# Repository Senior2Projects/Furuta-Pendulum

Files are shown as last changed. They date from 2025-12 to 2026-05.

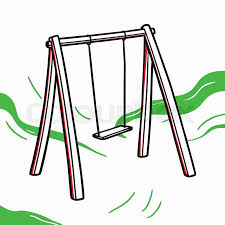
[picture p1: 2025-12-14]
Simulink_Bodies/Submission/Simulation_MCT411_T14/swing.jpg

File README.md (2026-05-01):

# Furuta Pendulum — Hybrid Control System

> **MCT411: Hybrid Control | Fall 2025 | Team 14**  
> Ain Shams University — Faculty of Engineering, Mechatronics Department

---

## 📖 Overview

This repository contains the MATLAB/Simulink implementation of a **hybrid control system** for the **Furuta (Rotary Inverted) Pendulum** — a nonlinear, underactuated mechatronic benchmark system. The control architecture combines two distinct strategies:

1. **Energy-Based Swing-Up Controller** — pumps energy into the pendulum to drive it from the natural downward-stable position to the upright equilibrium.
2. **Linear Quadratic Regulator (LQR)** — takes over once the pendulum is near upright, maintaining stability against small disturbances.

The full system is validated through both **MATLAB/Simulink simulation** and **Hardware-in-the-Loop (HIL)** testing on a physical prototype.

---

## 🧑‍💻 Team

| Name | ID | Contribution |
|---|---|---|
| Abdelghaffar Essam Abdelghaffar | 2100428 | Mechanical Design, LQR Implementation |
| Ingy Ahmed Sherif | 2100648 | LQR Implementation, Simulation Setup |
| Kareem Saleh Hassan | 2100909 | Mechanical Design, Swing-Up Implementation |
| Mariam Mohamed El Sebaey | 2100260 | Swing-Up Implementation, Simulation Setup |

---

## ⚙️ System Description

The Furuta Pendulum consists of two arms whose rotary axes are perpendicular to each other:

- **Arm 1 (Table/Rotor):** Horizontal arm driven by a DC motor. Angle: θ₁
- **Arm 2 (Pendulum):** Vertical free-swinging arm attached to the end of Arm 1. Angle: θ₂

The system is **underactuated** — only one torque input (the motor) controls two degrees of freedom.

### Hardware Components

| Component | Specification |
|---|---|
| Microcontroller | ESP32 |
| Motor Driver | H-Bridge (bidirectional) |
| Motor Encoder | 600 PPR (horizontal arm θ₁) |
| Pendulum Encoder | High-resolution (pendulum angle θ₂) |
| Power Supply | 12 V DC |
| Host Interface | USB/Serial → MATLAB/Simulink HIL |

### Physical Parameters

| Parameter | Symbol | Value |
|---|---|---|
| Pendulum mass | mᵣ | 0.018 kg |
| Pendulum COM to rotation axis | lᵣ | 0.0638 m |
| Pendulum moment of inertia | Jᵣ | 9.83 × 10⁻⁵ kg·m² |
| Table rotation axis to pendulum pivot | lₜ | 0.07 m |
| Rotor moment of inertia | J_motor | 0.0024 kg·m² |
| Motor resistance | Rₐ | 5.8466 Ω |
| Motor constants | kₜ = k_b | 0.048 V/rpm |
| Armature inductance | Lₐ | 9.15 × 10⁻⁴ H |

> Friction coefficients (motor, pendulum, table) were identified via **parameter estimation** rather than theoretical derivation.

---

## 🎮 Control Architecture

### State Vector

```
x = [θ₁  θ̇₁  θ₂  θ̇₂]ᵀ
```

### 1. Swing-Up Controller (Energy-Based)

The controller injects energy by oscillating the horizontal arm, guided by the difference between the current pendulum energy and the target energy at the upright equilibrium:

```
E  = ½ Jᵣ θ̇₁² + mᵣ g lᵣ (1 + cos θ₁)
Eᵣ = 2 mᵣ g lᵣ

u  = sat( k_swing · (Eᵣ − E) · θ̇₁ · cos θ₁ )
```

### 2. Balancing Controller (LQR)

The nonlinear Simscape Multibody model is linearized at the upright equilibrium using **Simulink Model Linearizer**, yielding the state-space matrices used for LQR design:

```
ẋ = Ax + Bu
```

**LQR Cost Function:**
```
J = ∫₀^∞ (xᵀQx + uᵀRu) dt
```

**Tuned Weights:**
```
Q = diag([1, 0.1, 100, 10])
R = 100
```

**Resulting Gain:**
```
K = [−0.0100  −0.0857  1.5880  0.1478]
u(t) = −K x(t)
```

### 3. Supervisory Logic (Stateflow)

A Stateflow chart manages transitions between control modes:

```
Swing_Up ──(|θ₂| ≤ 15°, |θ̇₂| ≤ 7)──► LQR
   ▲                                      │
   │                                      │ (|θ̇₂| ≥ 25 or timeout)
   │                                      ▼
   └────────(safe)────────────────── Recovery
```

| State | Condition |
|---|---|
| **Swing_Up** | Default; energy injection active |
| **LQR** | `\|θ₂\| ≤ 15°` and `\|θ̇₂\| ≤ 7 rad/s` |
| **Recovery** | `\|θ₂\| ≥ 110°` or speed exceeded; motor halted |

---

## 📁 Repository Structure

```
furuta-pendulum/
├── Simulink/
│   ├── SwingUp_Model.slx          # Energy-based swing-up subsystem
│   ├── LQR_Model.slx              # LQR balancing subsystem
│   ├── FullSystem_Model.slx       # Complete hybrid model with Stateflow
│   └── Pendulum_SimMechanics.slx  # Simscape Multibody physical model
├── MATLAB/
│   ├── parameters.m               # System physical parameters
│   ├── lqr_design.m               # LQR gain computation (K, Q, R)
│   └── linearize_model.m          # Linearization script
├── ESP32/
│   └── firmware/                  # Microcontroller code for HIL
├── Results/
│   ├── simulation_results.png
│   └── real_life_results.png
├── Report/
│   └── T14_Hybrid_Project_Report.pdf
└── README.md
```

---

## 🚀 Getting Started

### Requirements

- MATLAB R2022b or later
- Simulink
- Simscape & Simscape Multibody toolboxes
- Control System Toolbox (for `lqr()`)
- Stateflow

### Running the Simulation

1. Clone the repository:
   ```bash
   git clone https://github.com/<your-org>/furuta-pendulum.git
   cd furuta-pendulum
   ```

2. Open MATLAB and run the parameter initialization script:
   ```matlab
   run('MATLAB/parameters.m')
   ```

3. Open and run the full Simulink model:
   ```matlab
   open('Simulink/FullSystem_Model.slx')
   ```

4. Press **Run** in Simulink. Observe the four scopes: `PendAngle`, `PendVel`, `MotorAngle`, `MotorVel`.

### HIL Deployment (ESP32)

1. Flash the ESP32 firmware from `ESP32/firmware/`.
2. Connect via USB to the host PC.
3. In Simulink, configure the serial port in the ESP32 communication block.
4. Run the model in **External Mode** for real-time HIL control.

---

## 📊 Results Summary

| Metric | Simulation | Real-Life |
|---|---|---|
| Swing-up success | ✅ | ✅ |
| LQR stabilization | ✅ | ✅ |
| Settling time | ~7 s | ~12 s |
| Post-stabilization oscillations | Low | Slightly higher |

The discrepancies between simulation and real-life results are attributed to unmodeled joint backlash, high-frequency friction, and minor actuation delays.

---

## 📐 Controller Requirements

| Requirement | Specification |
|---|---|
| Swing-Up | Move pendulum to upright |
| Stabilization | Maintain upright via LQR |
| Sampling rate | ≥ 0.1 kHz |
| Torque limits | Motor saturation constraints |
| Robustness | Against small disturbances |

---

## 📚 References

- B. Yao, *"Modeling of Rotary Inverted Pendulum,"* 2022.
- K. J. Åström & K. Furuta, *"Swinging up a pendulum by energy control,"* Automatica, 2000.

---

## 📄 License

This project is submitted as academic coursework for MCT411 at Ain Shams University. All rights reserved by the authors.

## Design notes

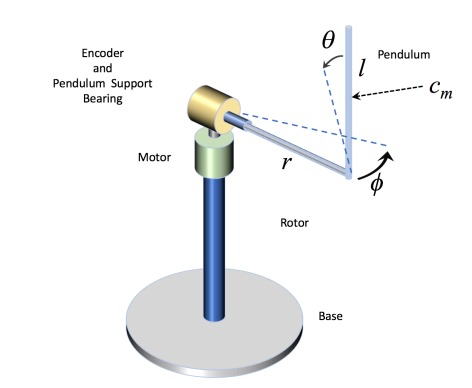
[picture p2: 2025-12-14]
Simulink_Bodies/Trial_5/Furuta_Schematic_1.jpg

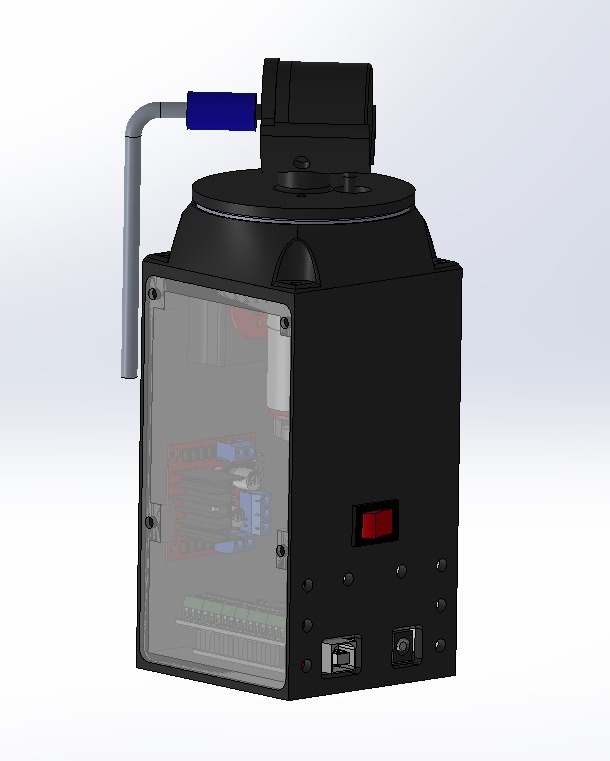
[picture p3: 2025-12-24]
Simulink_Bodies/Submission/Simulation_MCT411_T14/Model.jpeg

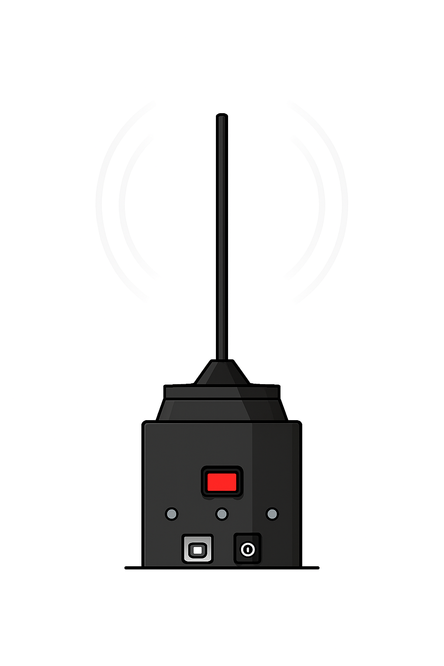
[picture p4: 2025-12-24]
Simulink_Bodies/Submission/Simulation_MCT411_T14/Model_Animated2.png

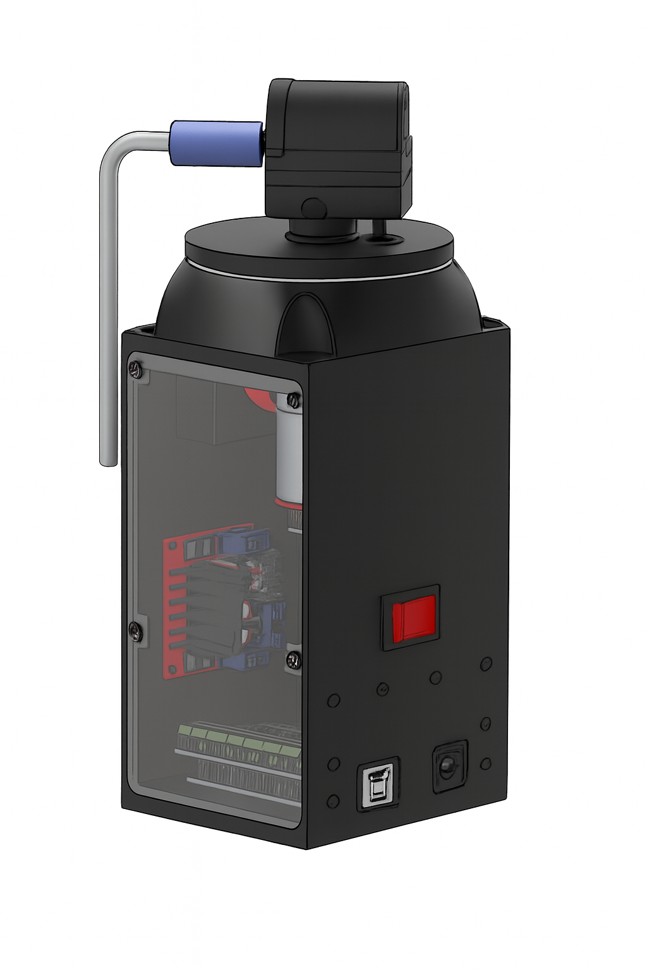
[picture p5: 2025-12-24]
Simulink_Bodies/Submission/Simulation_MCT411_T14/Model_Animated.png

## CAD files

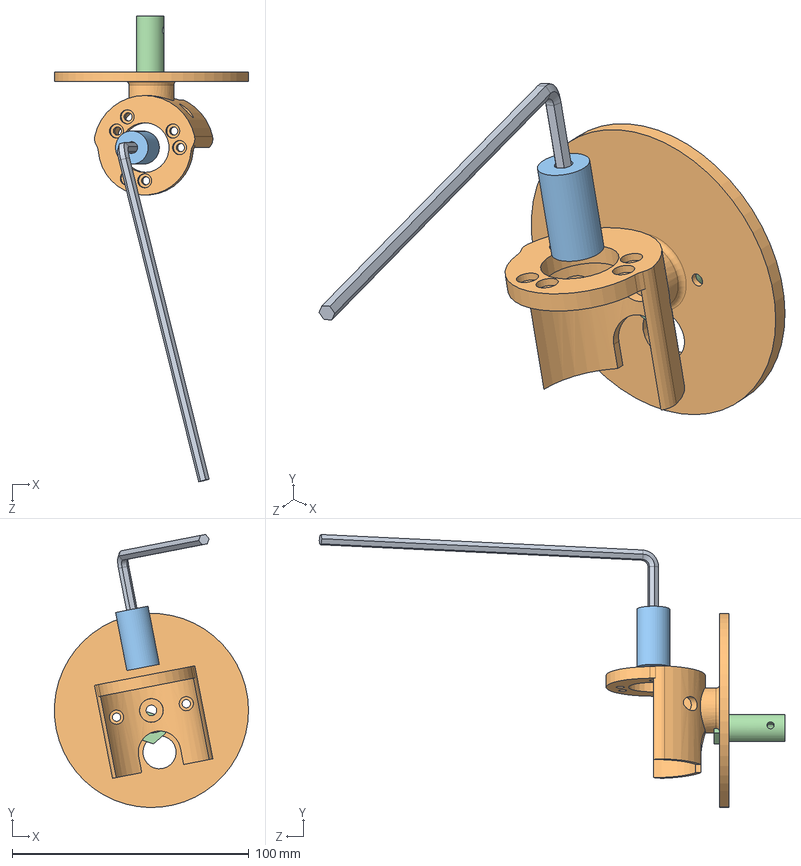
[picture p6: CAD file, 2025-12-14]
Simulink_Assembley/Furuta_Project_Assembelly.SLDASM
81.9 x 115.3 x 196.7 mm
hexa
coupler
Encoder Holder
rod

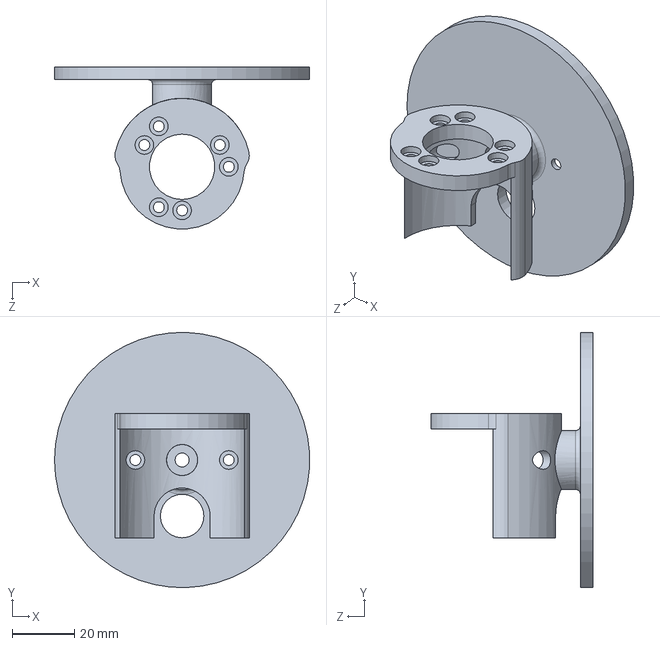
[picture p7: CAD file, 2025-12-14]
Encoder Holder.SLDPRT
81.9 x 82.0 x 51.9 mm

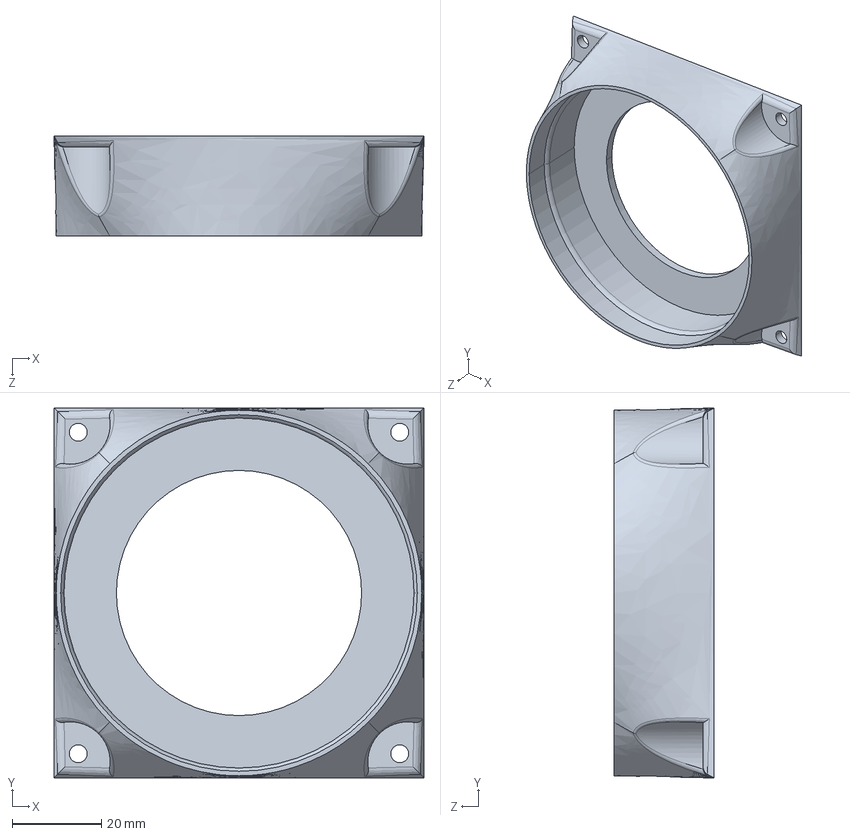
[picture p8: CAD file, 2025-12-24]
Simulink_Bodies/Submission/Simulation_MCT411_T14/Bearing Holder_Default_sldprt.STEP
83.0 x 83.0 x 22.5 mm

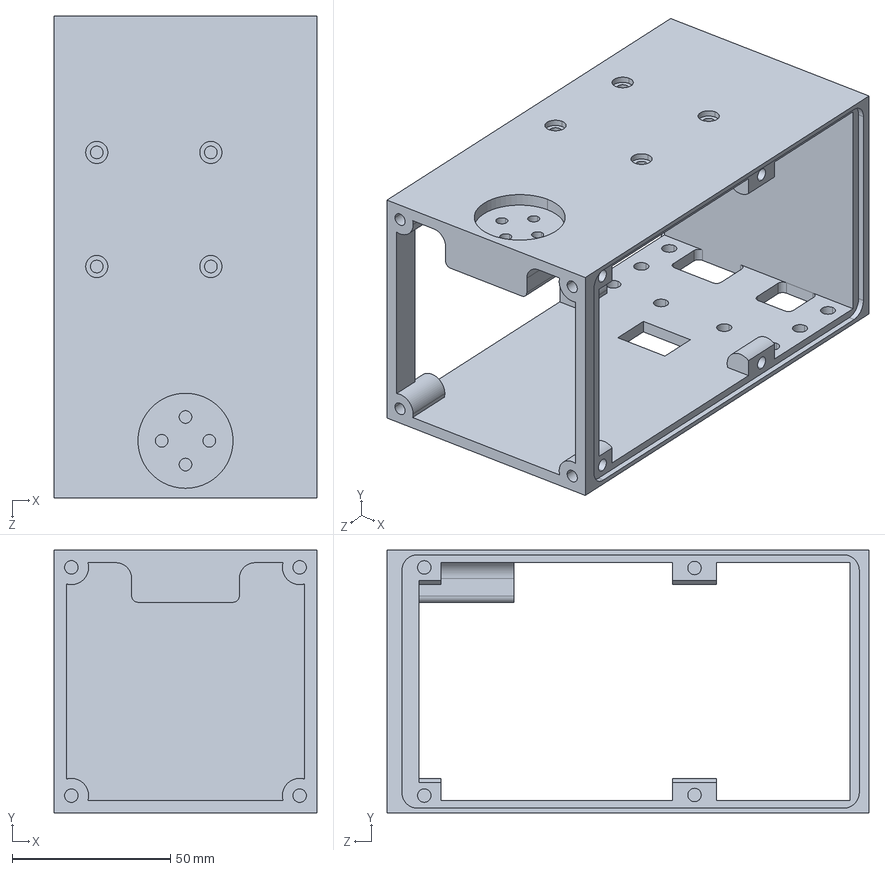
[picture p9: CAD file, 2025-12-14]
Simulink_Bodies/Trial_5/Box_Default_sldprt.STEP
83.0 x 83.0 x 152.0 mm

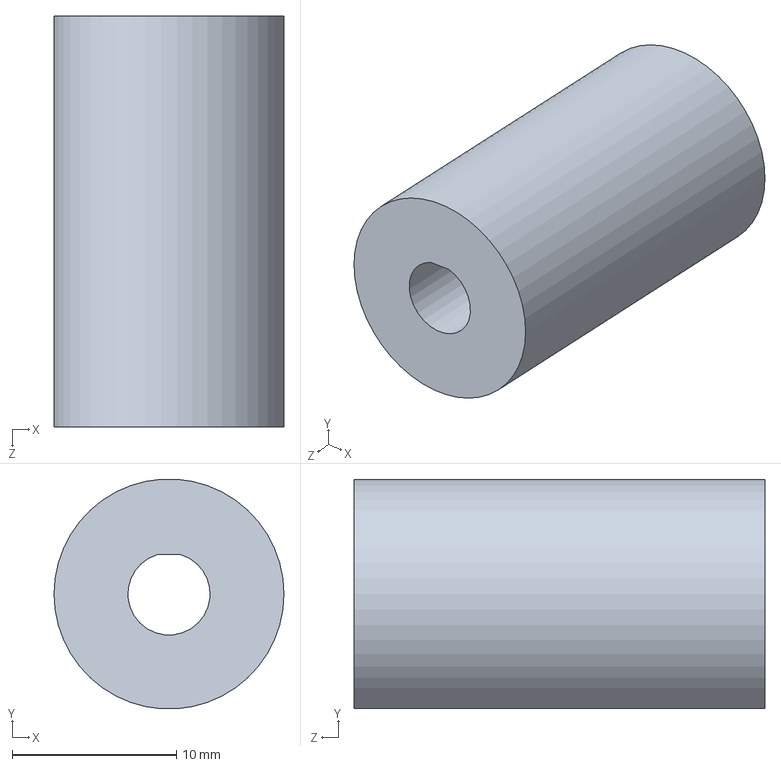
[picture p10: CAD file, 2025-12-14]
coupler.SLDPRT
14.0 x 14.0 x 25.0 mm

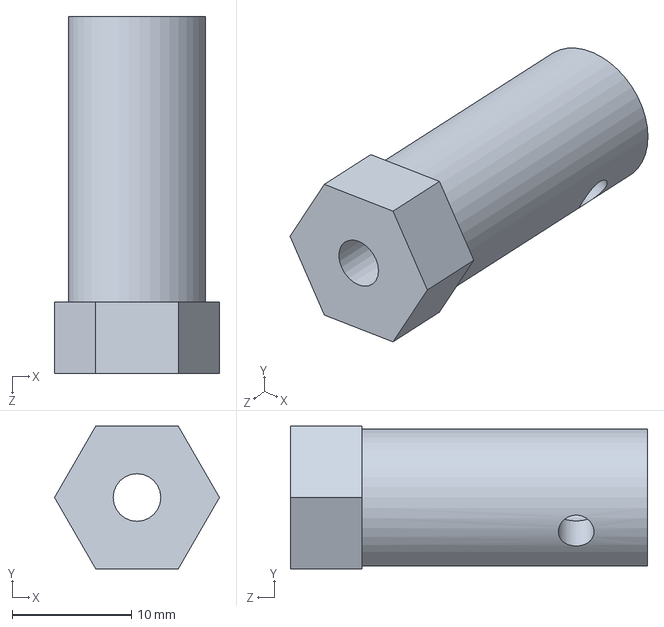
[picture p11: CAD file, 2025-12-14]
hexa.SLDPRT
13.9 x 12.0 x 30.0 mm

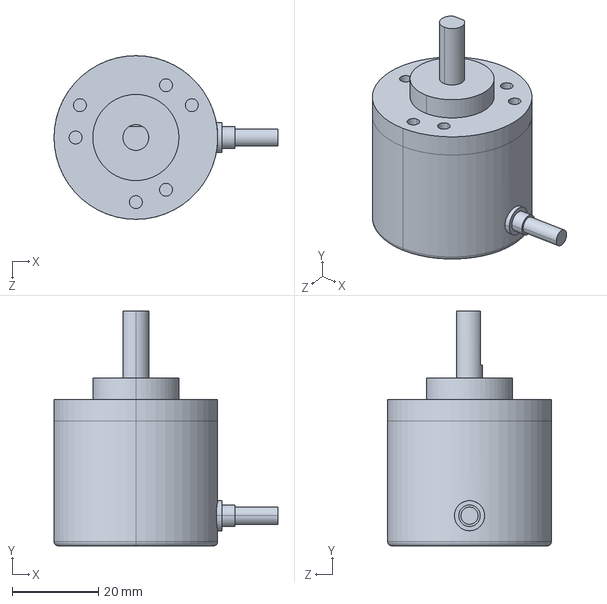
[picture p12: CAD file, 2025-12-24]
Simulink_Bodies/Submission/Simulation_MCT411_T14/encoder_Default_sldprt.STEP
52.0 x 54.5 x 38.0 mm

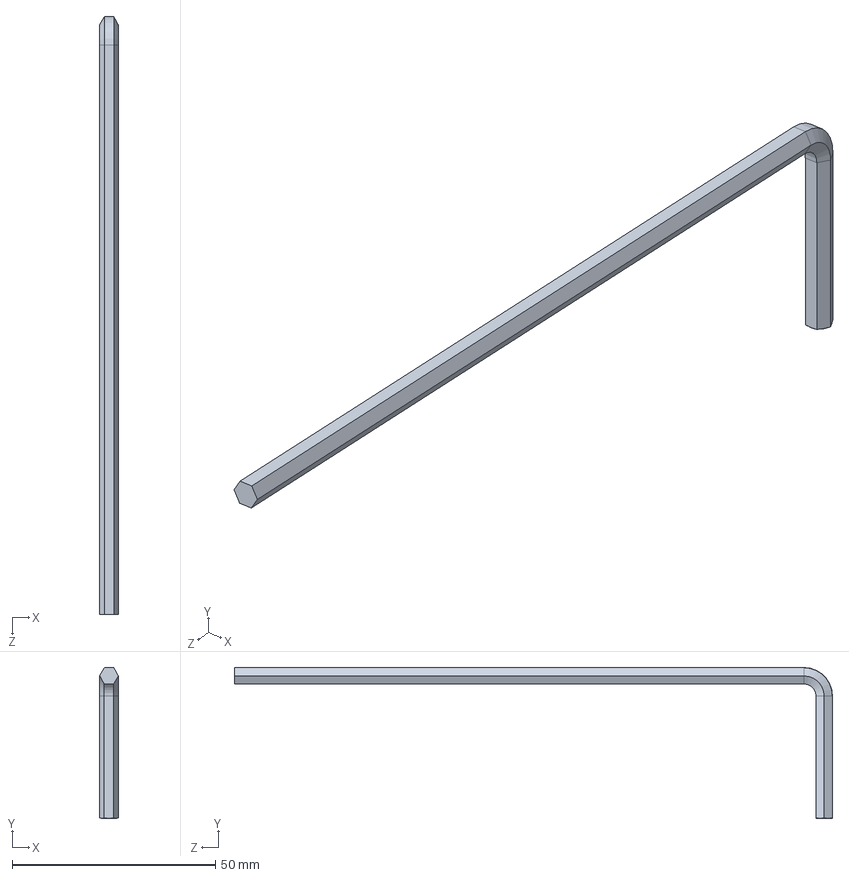
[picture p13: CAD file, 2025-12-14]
rod.SLDPRT
4.62 x 37.1 x 147.0 mm

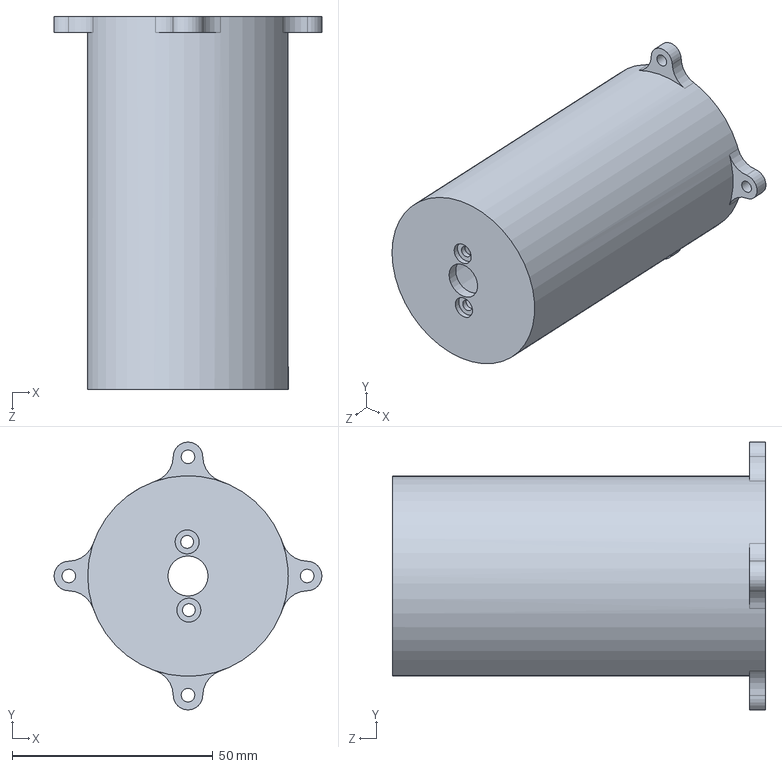
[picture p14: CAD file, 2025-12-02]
Motor Cover.SLDPRT
66.8 x 66.8 x 93.0 mm

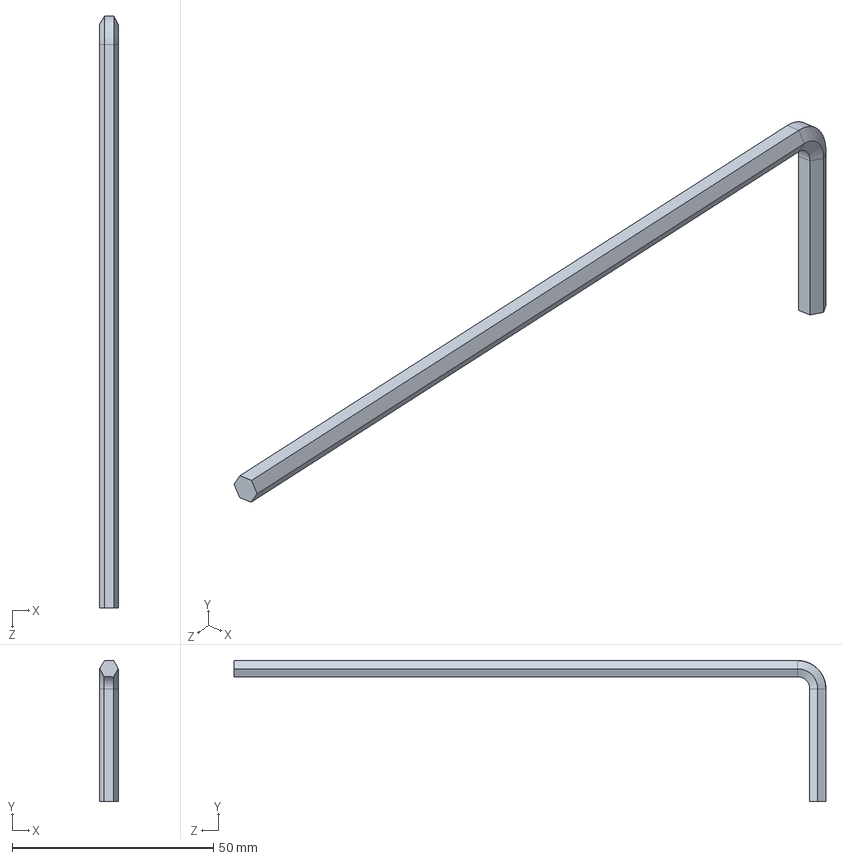
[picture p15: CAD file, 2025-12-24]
Simulink_Bodies/Submission/Simulation_MCT411_T14/rod_Default_sldprt.STEP
4.62 x 35.0 x 147.0 mm

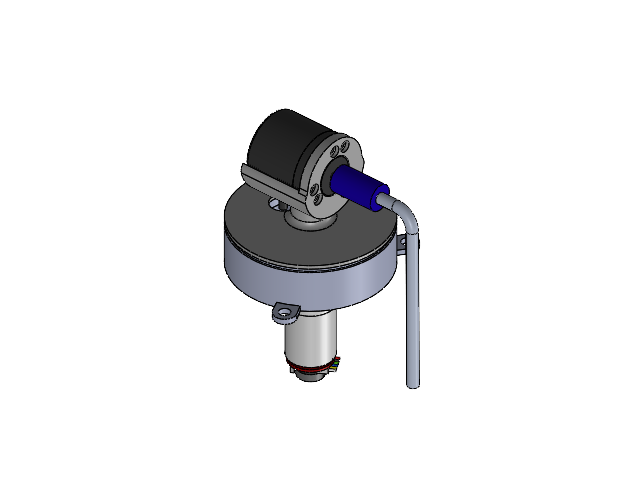
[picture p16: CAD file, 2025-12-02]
Furuta_Project_Assembelly.SLDASM
hexa
DCmotorr.stp
coupler
Encoder Holder
rod
encoder.stp
Bearing Holder
skf_bearing_51210_2_01
skf_bearing_51210_2_02
skf_bearing_51210_2_03

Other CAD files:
Simulink_Bodies/Submission/Simulation_MCT411_T14/Box_Default_sldprt.STEP
Simulink_Bodies/Trial_5/Encoder Holder_Default_sldprt.STEP
Simulink_Bodies/Trial_5/hexa_Default_sldprt.STEP
Simulink_Bodies/Submission/Simulation_MCT411_T14/hexa_Default_sldprt.STEP
Simulink_Bodies/Trial_5/coupler_Default_sldprt.STEP
Simulink_Bodies/Trial_5/Bearing Holder_Default_sldprt.STEP
Simulink_Bodies/Submission/Simulation_MCT411_T14/Encoder Holder_Default_sldprt.STEP
Simulink_Bodies/Submission/Simulation_MCT411_T14/Coupler_ext_Default_sldprt.STEP
Simulink_Bodies/Submission/Simulation_MCT411_T14/coupler_Default_sldprt.STEP
Simulink_Bodies/Trial_10/Bearing Holder_Default_sldprt.STEP
Simulink_Bodies/Trial_10/Box_Default_sldprt.STEP
Simulink_Bodies/Trial_10/Coupler_ext_Default_sldprt.STEP
Simulink_Bodies/Trial_10/Encoder Holder_Default_sldprt.STEP
Simulink_Bodies/Trial_10/coupler_Default_sldprt.STEP
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

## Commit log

2025-12-02 feat Bearing
    [Encoder Holder.SLDPRT, Furuta_Project_Assembelly.SLDASM, Motor Cover.SLDPRT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]
2025-12-13 feat Motor
2025-12-20 Trial 10
    [Bearing Holder_Default_sldprt.STEP, Box_Default_sldprt.STEP, Coupler_ext_Default_sldprt.STEP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]
2025-12-24 updated final simulation files
    [Bearing Holder_Default_sldprt.STEP, Box_Default_sldprt.STEP, Coupler_ext_Default_sldprt.STEP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]
